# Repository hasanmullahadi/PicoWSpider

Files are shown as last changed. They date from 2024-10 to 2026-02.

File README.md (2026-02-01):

# PicoWRobotV1.2



**Robotics Prototyping Board for Raspberry Pi Pico W**

4 DC Motor Drivers | MPU-6050 Gyro | 16-Channel PWM | Dual USB-C Power

---

## Overview

Unlock the full potential of your Raspberry Pi Pico W with this versatile prototyping board designed specifically for fast, efficient robotics development. Perfect for hobbyists, students, and engineers, this board comes preloaded with advanced features to support even the most ambitious robotics projects.

## Key Features

| Feature | Description |
|---|---|
| **4 DC Motor Drivers** | 2x TB6612FNG for controlling up to 4 DC motors with dedicated USB-C power |
| **Built-in Gyroscope** | MPU-6050 6-axis gyro and accelerometer for orientation and motion tracking |
| **16-Channel PWM Driver** | PCA9685PW for precise servo control with dedicated USB-C power |
| **Dual USB-C Power** | Ideal Diode (LM66200DRLR) for safe, independent power to motors and servos |
| **RGB LED** | Common anode LED for status indication and visual effects |
| **4 Push Buttons** | Tactile switches for real-time user input |
| **Sensor Headers** | Pre-configured headers for OLED, ultrasonic, and I2C expansion |

## Pin Diagrams

### Motor Drivers (TB6612FNG)
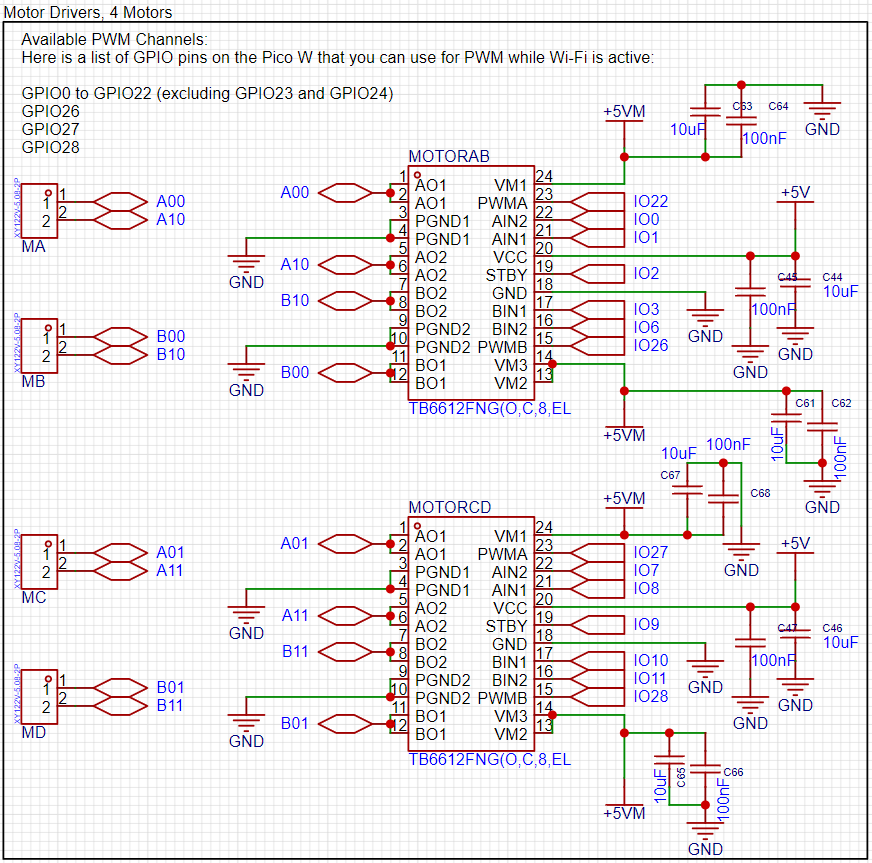
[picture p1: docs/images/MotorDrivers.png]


### Servo Connections (PCA9685)
<p>
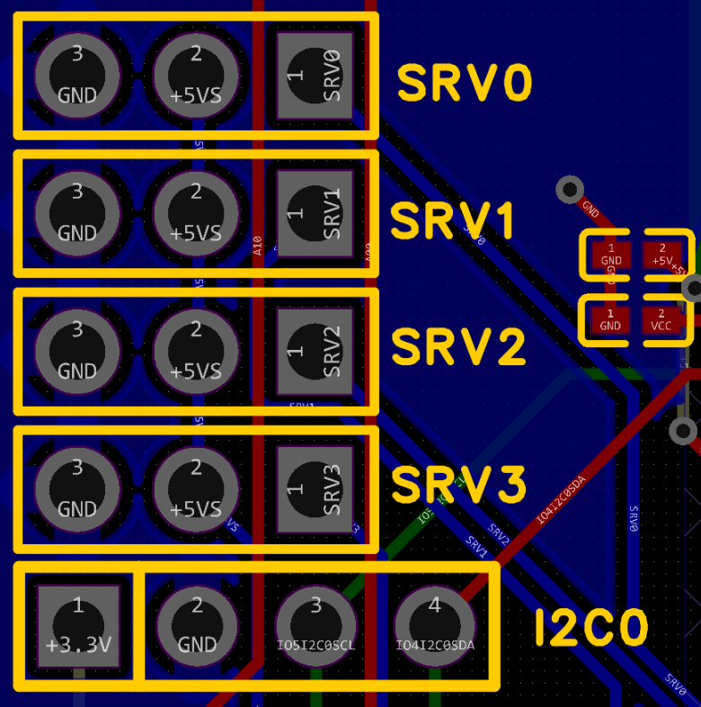
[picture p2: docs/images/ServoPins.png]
  
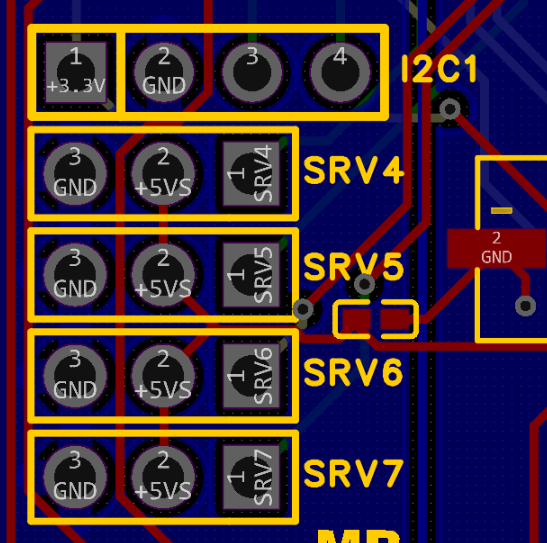
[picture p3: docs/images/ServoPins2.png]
  
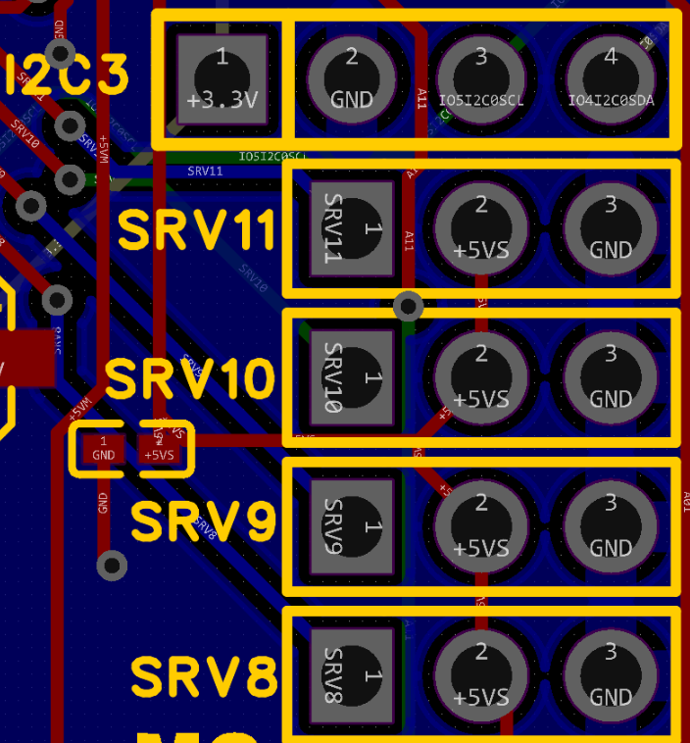
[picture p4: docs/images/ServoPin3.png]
  
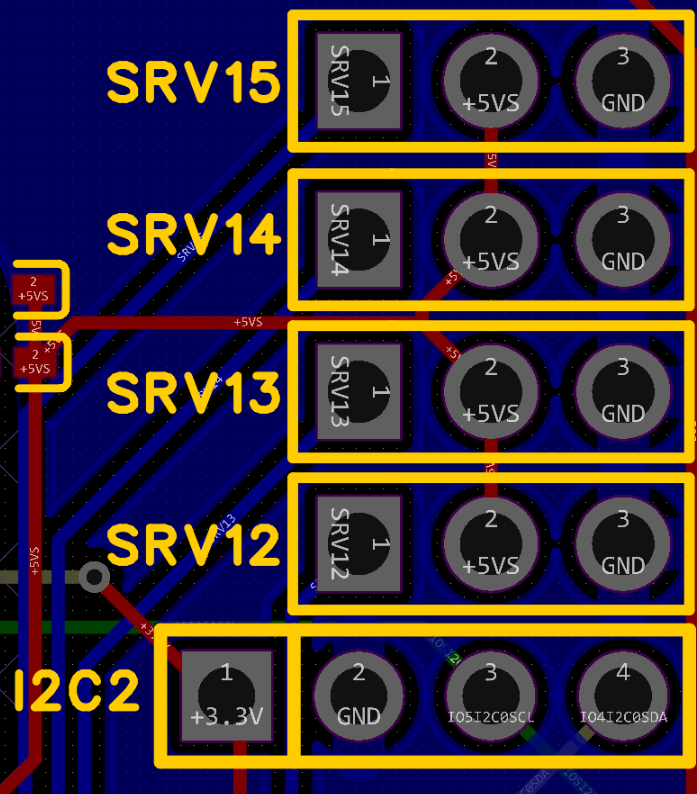
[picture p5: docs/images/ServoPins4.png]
  
</p>

### OLED Display
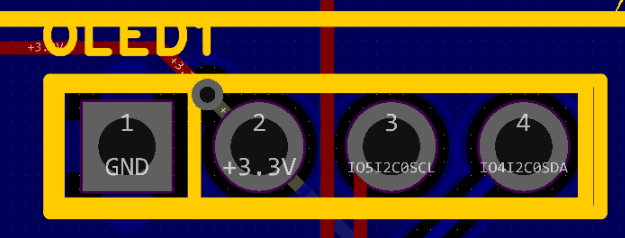
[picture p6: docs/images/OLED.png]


### Ultrasonic Sensor (HC-SR04)
<p>
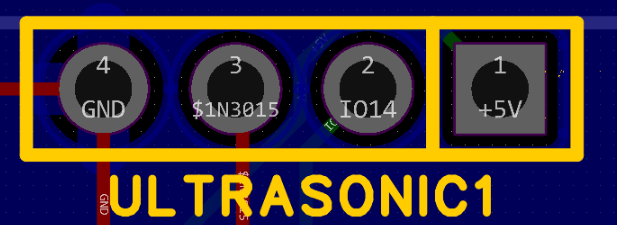
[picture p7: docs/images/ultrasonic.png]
  
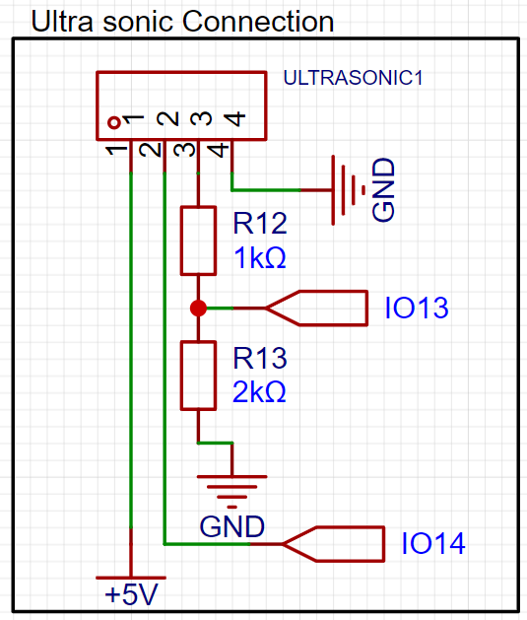
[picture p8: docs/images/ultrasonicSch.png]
  
</p>

### Temperature & Humidity Sensor (DHT22)
<p>
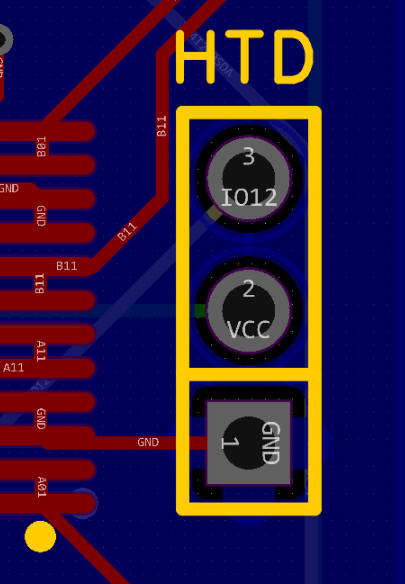
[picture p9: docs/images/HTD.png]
  
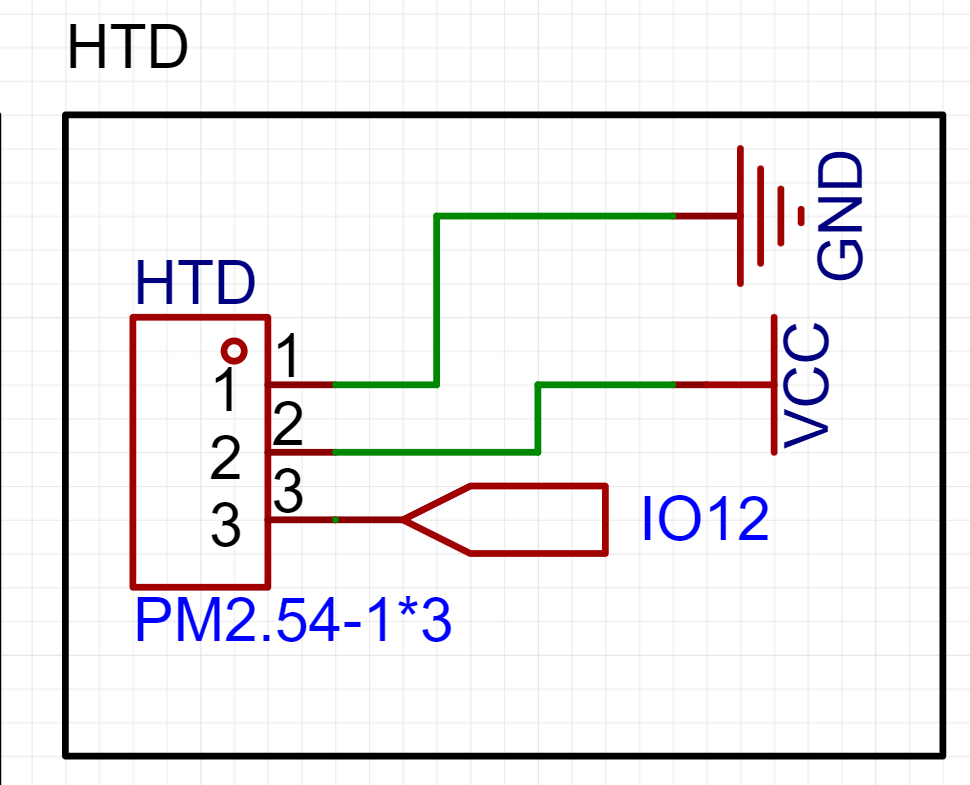
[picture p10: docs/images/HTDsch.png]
  
</p>

### RGB LED & Switches
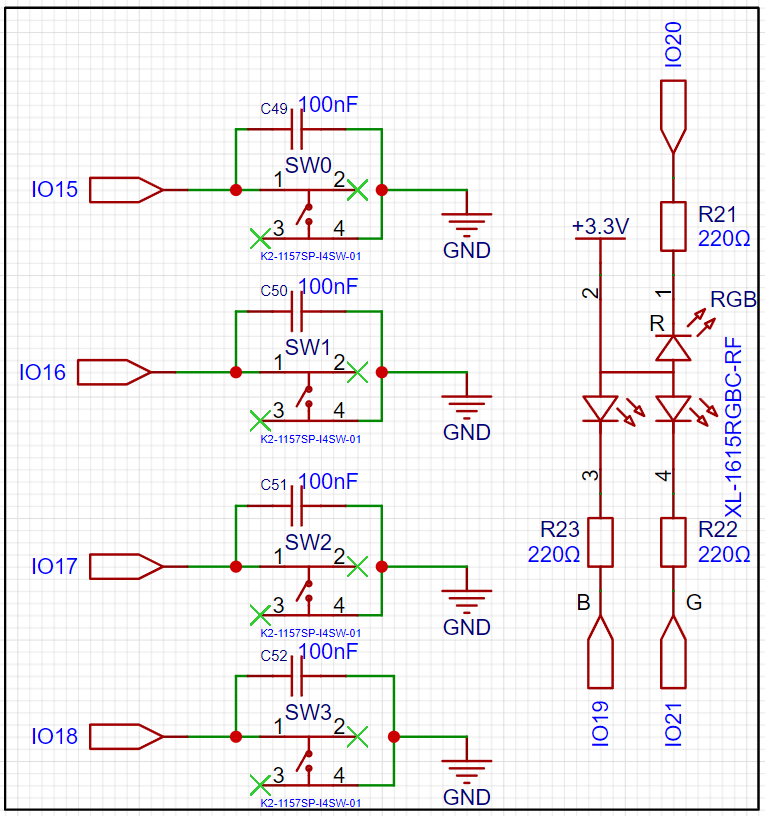
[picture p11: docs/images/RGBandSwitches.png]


## Dimensions

| Measurement | Value |
|---|---|
| PCB Size | 70.7mm x 110mm |
| PCB Weight | 58g (0.13 lbs) |
| Package Size | 20cm x 11cm x 13.5cm |
| Package Weight | 474g (1.05 lbs) |

## Bill of Materials

| # | Item | Description | Qty |
|---|---|---|-----|
| 1 | PicoWRobotV1.2 Board | Main prototyping board with motor drivers, gyro, PWM | 1 |
| 2 | RP Pico W | Raspberry Pi Pico W with pre-installed header pins | 1 |
| 3 | Ultrasonic Module | HC-SR04 distance sensor | 1 |
| 4 | TT Motor | DC motors for drive system | 4 |
| 5 | Mecanum Wheels | Omni-directional wheels with extensions and screws (2L, 2R) | 4 |
| 6 | DHT22 | Temperature and humidity sensor | 1 |
| 7 | OLED | 128x64 pixel display module | 1 |
| 8 | 3D Printed Body | Chassis (STL file: `docs/PicoWv1.stl`) | 1 |
| 9 | USB-C to USB Cable | For powering the board | 2 |
| 10 | USB to Micro USB Cable | For programming the Pico W | 1 |
| 11 | Zip Ties | For securing components and power bank | 5 |
| 12 | M3 Plastic Screws | With nuts for assembly | 3 |

## Getting Started

### Requirements
- Arduino IDE
- Power bank (not included) - must use standard USB output and be narrower than 6.5cm

### Arduino Libraries
Install via Library Manager:
- Adafruit GFX Library
- Adafruit SSD1306
- Adafruit MPU6050
- Adafruit PWM Servo Driver Library
- DHT sensor library

### Upload
1. Open `PicoWSpider.ino` in Arduino IDE
2. Select Board: **Raspberry Pi Pico W**
3. Connect via USB and upload

### WiFi Control
The robot creates a WiFi access point on boot:
- **SSID:** PicoW
- **Password:** 12345678
- **Control Interface:** Connect and navigate to the IP shown on the OLED display

## 3D Model

The chassis STL file (`docs/PicoWv1.stl`) is included for 3D printing your own robot body.

## Author

**Hasan Ismail** · [@hasanmullahadi](https://github.com/hasanmullahadi)

I'm a passionate hobbyist who loves creating and building projects, especially in robotics. My goal with this development board is to make it as fast and easy as possible for anyone to start coding and experimenting with robotics.

Your feedback and suggestions are welcome for future versions!

**Contact:** [Open an issue](https://github.com/hasanmullahadi/PicoWSpider/issues) or reach out via GitHub

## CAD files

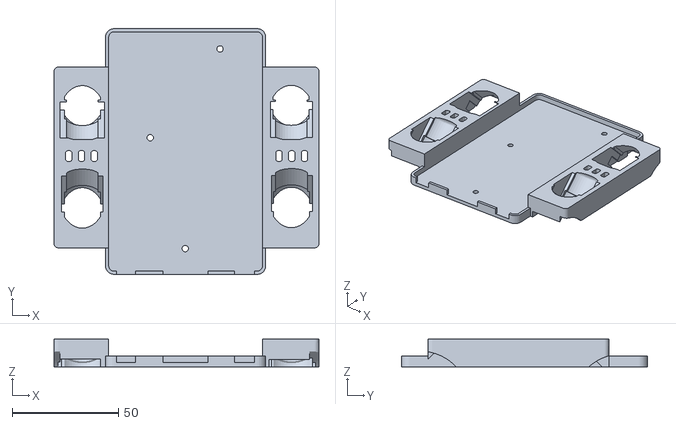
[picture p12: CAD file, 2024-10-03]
docs/PicoWv1.stl
124.8 x 115.7 x 13.1

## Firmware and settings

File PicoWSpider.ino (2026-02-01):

#include <Adafruit_GFX.h>
#include <Adafruit_SSD1306.h>
#include <Adafruit_MPU6050.h>

#include "src/web/RobotWebServer.h"
#include "src/actuators/MotorController.h"
#include "src/actuators/ServoController.h"
#include "src/sensors/DHTSensor.h"
#include "src/sensors/Ultrasonic.h"

// ============================================================================
// Configuration Constants
// ============================================================================

// WiFi
const char *WIFI_SSID = "PicoW";
const char *WIFI_PASSWORD = "12345678";

// Motor speeds
const uint8_t MOTOR_SPEED_NORMAL = 150;
const uint8_t MOTOR_SPEED_SLOW = 100;
const uint8_t MOTOR_SPEED_FAST = 200;

// Timing intervals (ms)
const unsigned long DISPLAY_UPDATE_INTERVAL = 250;
const unsigned long SERVO_UPDATE_INTERVAL = 1000;
const unsigned long OBSTACLE_CLEAR_DELAY = 1000;
const unsigned long TURN_360_DURATION = 3000;

// Obstacle detection threshold (cm)
const float OBSTACLE_DISTANCE_CM = 30.0;

// OLED display
const int SCREEN_WIDTH = 128;
const int SCREEN_HEIGHT = 64;
const int SCREEN_ADDRESS = 0x3C;

// ============================================================================
// Pin Definitions
// ============================================================================

// Motor Controller AB
#define PWMA_PIN 22
#define AIN1_PIN 1
#define AIN2_PIN 0
#define PWMB_PIN 26
#define BIN1_PIN 3
#define BIN2_PIN 6
#define STBY_PIN_AB 2

// Motor Controller CD
#define PWMC_PIN 27
#define CIN1_PIN 8
#define CIN2_PIN 7
#define PWMD_PIN 28
#define DIN1_PIN 10
#define DIN2_PIN 11
#define STBY_PIN_CD 9

// Sensors
#define TRIG_PIN 14
#define ECHO_PIN 13
#define DHT_PIN 12
#define DHT_TYPE DHT22

// User interface
#define BUTTON_0 15
#define BUTTON_1 16
#define BUTTON_2 17
#define BUTTON_3 18
#define LED_RED 20
#define LED_GREEN 21
#define LED_BLUE 19

// Servo channels
#define SRV0 0
#define SRV15 15

// ============================================================================
// Global Objects
// ============================================================================

RobotWebServer robotServer(WIFI_SSID, WIFI_PASSWORD, 80, true);
MotorController motorControllerAB(PWMA_PIN, AIN2_PIN, AIN1_PIN, PWMB_PIN, BIN2_PIN, BIN1_PIN, STBY_PIN_AB);
MotorController motorControllerCD(PWMC_PIN, CIN1_PIN, CIN2_PIN, PWMD_PIN, DIN1_PIN, DIN2_PIN, STBY_PIN_CD);
Ultrasonic ultrasonic(TRIG_PIN, ECHO_PIN);
ServoController servoController(0x60);
DHTSensor dhtSensor(DHT_PIN, DHT_TYPE);
Adafruit_SSD1306 display(SCREEN_WIDTH, SCREEN_HEIGHT, &Wire, -1);
Adafruit_MPU6050 mpu;

// State variables
unsigned long previousDisplayMillis = 0;
unsigned long previousServoMillis = 0;
unsigned long obstacleClearMillis = 0;
unsigned long turnStartMillis = 0;
float distance = 0;
float humidity = 0;
float temperature = 0;
int brightness = 255;
bool isSpinning = false;
bool spinDirection = false;
bool isTurning = false;
bool servoMoveRight = false;

// ============================================================================
// Setup
// ============================================================================

void setup() {
    Serial.begin(115200);

    // Initialize MPU6050
    if (!mpu.begin()) {
        Serial.println("Failed to find MPU6050 chip");
        while (1) delay(10);
    }
    Serial.println("MPU6050 Found!");

    mpu.setHighPassFilter(MPU6050_HIGHPASS_0_63_HZ);
    mpu.setMotionDetectionThreshold(1);
    mpu.setMotionDetectionDuration(20);
    mpu.setInterruptPinLatch(true);
    mpu.setInterruptPinPolarity(true);
    mpu.setMotionInterrupt(true);

    // Initialize sensors
    ultrasonic.begin();
    dhtSensor.begin();

    // Initialize buttons
    pinMode(BUTTON_0, INPUT_PULLUP);
    pinMode(BUTTON_1, INPUT_PULLUP);
    pinMode(BUTTON_2, INPUT_PULLUP);
    pinMode(BUTTON_3, INPUT_PULLUP);

    // Initialize RGB LED (common anode - inverted)
    pinMode(LED_RED, OUTPUT);
    pinMode(LED_GREEN, OUTPUT);
    pinMode(LED_BLUE, OUTPUT);

    // Initialize I2C and OLED
    Wire.begin();
    if (!display.begin(SSD1306_SWITCHCAPVCC, SCREEN_ADDRESS)) {
        for (;;);
    }

    display.clearDisplay();
    display.setTextSize(1);
    display.setTextColor(SSD1306_WHITE);
    display.setCursor(0, 0);
    display.println(F("Mini Robot"));
    display.display();
    delay(2000);

    // Initialize servo controller
    servoController.begin();
    servoController.moveServo(SRV0, 90);
    servoController.moveServo(SRV15, 90);

    // Initialize motor controllers
    motorControllerAB.begin();
    motorControllerCD.begin();
    delay(1000);

    // Start web server
    robotServer.begin();

    String ipAddress = WiFi.localIP().toString();
    Serial.print("IP Address: ");
    Serial.println(ipAddress);

    display.clearDisplay();
    display.setCursor(0, 0);
    display.println(F("Connected to WiFi"));
    display.setCursor(0, 20);
    display.println(F("IP Address:"));
    display.setCursor(0, 35);
    display.println(ipAddress);
    display.display();

    // Set web server callbacks
    robotServer.setMoveForwardCallback(moveForward);
    robotServer.setMoveBackwardCallback(moveBackward);
    robotServer.setStopCallback(stopMotors);
    robotServer.setSpinCallback(spin);
}

// ============================================================================
// Main Loop
// ============================================================================

void loop() {
    unsigned long currentMillis = millis();

    // Update display and sensors
    if (currentMillis - previousDisplayMillis >= DISPLAY_UPDATE_INTERVAL) {
        previousDisplayMillis = currentMillis;
        updateDisplayAndSensors();
    }

    // Update servo positions
    if (currentMillis - previousServoMillis >= SERVO_UPDATE_INTERVAL) {
        previousServoMillis = currentMillis;
        updateServos();
    }

    // Update IMU data
    if (mpu.getMotionInterruptStatus()) {
        sensors_event_t a, g, temp;
        mpu.getEvent(&a, &g, &temp);
        robotServer.setAcceleration(a.acceleration.x, a.acceleration.y, a.acceleration.z);
        robotServer.setGyroscope(g.gyro.x, g.gyro.y, g.gyro.z);
    }

    // Update web server data
    updateLEDsFromServer();
    robotServer.setDistance(distance);
    robotServer.setDHTValues(temperature, humidity);
    robotServer.handleClient();
}

// ============================================================================
// Display & Sensor Updates
// ============================================================================

void updateDisplayAndSensors() {
    display.clearDisplay();

    // Read sensors
    temperature = dhtSensor.readTemperature();
    humidity = dhtSensor.readHumidity();
    distance = ultrasonic.getDistance();

    // Display temperature and humidity
    display.setTextSize(1);
    display.setTextColor(SSD1306_WHITE);
    display.setCursor(0, 0);
    display.print(F("T: "));
    display.print(temperature);
    display.print(F("C, H: "));
    display.print(humidity);
    display.println(F("%"));

    // Handle button presses
    handleButtons();

    // Display distance
    display.setCursor(0, 32);
    display.print(F("Distance: "));
    display.print(distance);
    display.println(F(" cm"));

    // Display IP
    display.setCursor(0, 48);
    display.print(F("IP: "));
    display.println(WiFi.localIP().toString());

    display.display();
}

void handleButtons() {
    if (digitalRead(BUTTON_0) == LOW) {
        displayButton(0);
        setRGB(LOW, HIGH, HIGH);  // Red
    } else if (digitalRead(BUTTON_1) == LOW) {
        displayButton(1);
        setRGB(HIGH, LOW, HIGH);  // Green
    } else if (digitalRead(BUTTON_2) == LOW) {
        displayButton(2);
        setRGB(HIGH, HIGH, LOW);  // Blue
    } else if (digitalRead(BUTTON_3) == LOW) {
        displayButton(3);
        toggleBrightness();
    }
}

void displayButton(int buttonNumber) {
    display.setCursor(0, 16);
    display.print(F("Button "));
    display.print(buttonNumber);
    display.println(F(" pressed"));
}

// ============================================================================
// LED Control
// ============================================================================

void setRGB(int red, int green, int blue) {
    // Common anode: invert values
    analogWrite(LED_RED, 255 - red);
    analogWrite(LED_GREEN, 255 - green);
    analogWrite(LED_BLUE, 255 - blue);
}

void toggleBrightness() {
    brightness = (brightness == 255) ? 128 : 255;
    analogWrite(LED_RED, brightness);
    analogWrite(LED_GREEN, brightness);
    analogWrite(LED_BLUE, brightness);
}

void updateLEDsFromServer() {
    uint8_t r, g, b;
    robotServer.getRGBValue(0, r, g, b);
    setRGB(r, g, b);
}

// ============================================================================
// Servo Control
// ============================================================================

void updateServos() {
    if (servoMoveRight) {
        servoController.moveRight(SRV0);
        servoController.moveRight(SRV15);
    } else {
        servoController.moveLeft(SRV0);
        servoController.moveLeft(SRV15);
    }
    servoMoveRight = !servoMoveRight;
}

// ============================================================================
// Motor Control - Basic Movements
// ============================================================================

void moveForward() {
    motorControllerAB.motorAForward(MOTOR_SPEED_NORMAL);
    motorControllerAB.motorBForward(MOTOR_SPEED_NORMAL);
    motorControllerCD.motorAForward(MOTOR_SPEED_NORMAL);
    motorControllerCD.motorBForward(MOTOR_SPEED_NORMAL);
}

void moveBackward() {
    motorControllerAB.motorABackward(MOTOR_SPEED_NORMAL);
    motorControllerAB.motorBBackward(MOTOR_SPEED_NORMAL);
    motorControllerCD.motorABackward(MOTOR_SPEED_NORMAL);
    motorControllerCD.motorBBackward(MOTOR_SPEED_NORMAL);
}

void strafeRight() {
    motorControllerAB.motorAForward(MOTOR_SPEED_NORMAL);
    motorControllerAB.motorBBackward(MOTOR_SPEED_NORMAL);
    motorControllerCD.motorABackward(MOTOR_SPEED_NORMAL);
    motorControllerCD.motorBForward(MOTOR_SPEED_NORMAL);
}

void strafeLeft() {
    motorControllerAB.motorABackward(MOTOR_SPEED_NORMAL);
    motorControllerAB.motorBForward(MOTOR_SPEED_NORMAL);
    motorControllerCD.motorAForward(MOTOR_SPEED_NORMAL);
    motorControllerCD.motorBBackward(MOTOR_SPEED_NORMAL);
}

void stopMotors() {
    motorControllerAB.motorAStop();
    motorControllerAB.motorBStop();
    motorControllerCD.motorAStop();
    motorControllerCD.motorBStop();
}

// ============================================================================
// Motor Control - Spinning
// ============================================================================

void spin() {
    spinLeftSlow();
}

void spinLeftSlow() {
    motorControllerAB.motorAForward(MOTOR_SPEED_SLOW);
    motorControllerAB.motorBForward(MOTOR_SPEED_SLOW);
    motorControllerCD.motorABackward(MOTOR_SPEED_SLOW);
    motorControllerCD.motorBBackward(MOTOR_SPEED_SLOW);
}

void spinRightSlow() {
    motorControllerAB.motorABackward(MOTOR_SPEED_SLOW);
    motorControllerAB.motorBBackward(MOTOR_SPEED_SLOW);
    motorControllerCD.motorAForward(MOTOR_SPEED_SLOW);
    motorControllerCD.motorBForward(MOTOR_SPEED_SLOW);
}

void performSlowSpin(bool direction) {
    if (direction) {
        spinRightSlow();
    } else {
        spinLeftSlow();
    }
}

// ============================================================================
// Autonomous Navigation
// ============================================================================

void movingAround() {
    unsigned long currentMillis = millis();

    if (ultrasonic.getDistance() < OBSTACLE_DISTANCE_CM) {
        if (!isSpinning) {
            isSpinning = true;
            spinDirection = random(0, 2);
        }
        performSlowSpin(spinDirection);
        obstacleClearMillis = currentMillis;
    } else {
        if (isSpinning && (currentMillis - obstacleClearMillis >= OBSTACLE_CLEAR_DELAY)) {
            isSpinning = false;
        }
        if (!isSpinning) {
            moveForward();
        }
    }
}

void perform360Turn() {
    unsigned long currentMillis = millis();

    if (!isTurning) {
        motorControllerAB.motorAForward(MOTOR_SPEED_NORMAL);
        motorControllerAB.motorBBackward(MOTOR_SPEED_NORMAL);
        motorControllerCD.motorABackward(MOTOR_SPEED_NORMAL);
        motorControllerCD.motorBForward(MOTOR_SPEED_NORMAL);
        turnStartMillis = currentMillis;
        isTurning = true;
    }

    if (isTurning && (currentMillis - turnStartMillis >= TURN_360_DURATION)) {
        stopMotors();
        isTurning = false;
    }
}

// ============================================================================
// Testing & Diagnostics
// ============================================================================

void displayStatus(const char *status) {
    display.clearDisplay();
    display.setTextSize(1);
    display.setTextColor(SSD1306_WHITE);
    display.setCursor(0, 0);
    display.println(F("Status:"));
    display.println(status);
    display.display();
}

void testMotors() {
    displayStatus("Testing Motor A");
    motorControllerAB.softStartA(128);
    delay(1000);
    motorControllerAB.softStopA();
    delay(1000);

    displayStatus("Testing Motor B");
    motorControllerAB.softStartB(128);
    delay(1000);
    motorControllerAB.softStopB();
    delay(1000);

    displayStatus("Testing Motor C");
    motorControllerCD.softStartA(128);
    delay(1000);
    motorControllerCD.softStopA();
    delay(1000);

    displayStatus("Testing Motor D");
    motorControllerCD.softStartB(128);
    delay(1000);
    motorControllerCD.softStopB();
    delay(1000);
}

void forwardTest() {
    const char* motorNames[] = {"Front Left (A)", "Back Left (B)", "Back Right (C)", "Front Right (D)"};

    displayStatus(motorNames[0]);
    motorControllerAB.motorAForward(MOTOR_SPEED_FAST);
    delay(2000);
    motorControllerAB.motorAStop();
    delay(1000);

    displayStatus(motorNames[1]);
    motorControllerAB.motorBForward(MOTOR_SPEED_FAST);
    delay(2000);
    motorControllerAB.motorBStop();
    delay(1000);

    displayStatus(motorNames[2]);
    motorControllerCD.motorAForward(MOTOR_SPEED_FAST);
    delay(2000);
    motorControllerCD.motorAStop();
    delay(1000);

    displayStatus(motorNames[3]);
    motorControllerCD.motorBForward(MOTOR_SPEED_FAST);
    delay(2000);
    motorControllerCD.motorBStop();
    delay(1000);

    displayStatus("Forward Test Complete");
    delay(2000);
}

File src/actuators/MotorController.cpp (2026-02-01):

#include "MotorController.h"

MotorController::MotorController(uint8_t pwmaPin, uint8_t ain1Pin, uint8_t ain2Pin,
                                 uint8_t pwmbPin, uint8_t bin1Pin, uint8_t bin2Pin,
                                 uint8_t stbyPin)
    : _pwmaPin(pwmaPin), _ain1Pin(ain1Pin), _ain2Pin(ain2Pin),
      _pwmbPin(pwmbPin), _bin1Pin(bin1Pin), _bin2Pin(bin2Pin),
      _stbyPin(stbyPin) {}

void MotorController::begin() {
    pinMode(_pwmaPin, OUTPUT);
    pinMode(_ain1Pin, OUTPUT);
    pinMode(_ain2Pin, OUTPUT);
    pinMode(_pwmbPin, OUTPUT);
    pinMode(_bin1Pin, OUTPUT);
    pinMode(_bin2Pin, OUTPUT);
    pinMode(_stbyPin, OUTPUT);
    wake();
}

void MotorController::motorAForward(uint8_t speed) {
    motorControl(_pwmaPin, _ain1Pin, _ain2Pin, speed, true);
}

void MotorController::motorABackward(uint8_t speed) {
    motorControl(_pwmaPin, _ain1Pin, _ain2Pin, speed, false);
}

void MotorController::motorAStop() {
    analogWrite(_pwmaPin, 0);
}

void MotorController::motorBForward(uint8_t speed) {
    motorControl(_pwmbPin, _bin1Pin, _bin2Pin, speed, true);
}

void MotorController::motorBBackward(uint8_t speed) {
    motorControl(_pwmbPin, _bin1Pin, _bin2Pin, speed, false);
}

void MotorController::motorBStop() {
    analogWrite(_pwmbPin, 0);
}

void MotorController::standby() {
    digitalWrite(_stbyPin, LOW);
}

void MotorController::wake() {
    digitalWrite(_stbyPin, HIGH);
}

void MotorController::softStartA(uint8_t targetSpeed, uint8_t incrementDelay) {
    static unsigned long previousMillis = 0;
    static uint8_t currentSpeed = 0;
    unsigned long currentMillis = millis();

    if (currentSpeed < targetSpeed && (currentMillis - previousMillis >= incrementDelay)) {
        previousMillis = currentMillis;
        currentSpeed += SPEED_INCREMENT;
        motorAForward(currentSpeed);
    }
}

void MotorController::softStopA(uint8_t decrementDelay) {
    static unsigned long previousMillis = 0;
    static uint8_t currentSpeed = analogRead(_pwmaPin);
    unsigned long currentMillis = millis();

    if (currentSpeed > 0 && (currentMillis - previousMillis >= decrementDelay)) {
        previousMillis = currentMillis;
        currentSpeed = (currentSpeed > SPEED_INCREMENT) ? currentSpeed - SPEED_INCREMENT : 0;
        motorAForward(currentSpeed);
    }
    if (currentSpeed == 0) {
        motorAStop();
    }
}

void MotorController::softStartB(uint8_t targetSpeed, uint8_t incrementDelay) {
    static unsigned long previousMillis = 0;
    static uint8_t currentSpeed = 0;
    unsigned long currentMillis = millis();

    if (currentSpeed < targetSpeed && (currentMillis - previousMillis >= incrementDelay)) {
        previousMillis = currentMillis;
        currentSpeed += SPEED_INCREMENT;
        motorBForward(currentSpeed);
    }
}

void MotorController::softStopB(uint8_t decrementDelay) {
    static unsigned long previousMillis = 0;
    static uint8_t currentSpeed = analogRead(_pwmbPin);
    unsigned long currentMillis = millis();

    if (currentSpeed > 0 && (currentMillis - previousMillis >= decrementDelay)) {
        previousMillis = currentMillis;
        currentSpeed = (currentSpeed > SPEED_INCREMENT) ? currentSpeed - SPEED_INCREMENT : 0;
        motorBForward(currentSpeed);
    }
    if (currentSpeed == 0) {
        motorBStop();
    }
}

void MotorController::motorControl(uint8_t pwmPin, uint8_t in1Pin, uint8_t in2Pin,
                                   uint8_t speed, bool forward) {
    analogWrite(pwmPin, speed);
    if (forward) {
        digitalWrite(in1Pin, HIGH);
        digitalWrite(in2Pin, LOW);
    } else {
        digitalWrite(in1Pin, LOW);
        digitalWrite(in2Pin, HIGH);
    }
}

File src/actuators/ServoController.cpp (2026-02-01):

#include "ServoController.h"

ServoController::ServoController(uint8_t addr) : pwm(Adafruit_PWMServoDriver(addr)) {}

void ServoController::begin() {
    pwm.begin();
    pwm.setPWMFreq(SERVO_FREQ_HZ);
}

void ServoController::moveServo(uint8_t servoNum, uint16_t angle) {
    uint16_t clampedAngle = constrain(angle, SERVO_ANGLE_MIN, SERVO_ANGLE_MAX);
    uint16_t pulseLength = map(clampedAngle, SERVO_ANGLE_MIN, SERVO_ANGLE_MAX,
                               SERVO_MIN_PULSE, SERVO_MAX_PULSE);
    pwm.setPWM(servoNum, 0, pulseLength);
}

void ServoController::moveLeft(uint8_t servoNum) {
    moveServo(servoNum, SERVO_ANGLE_MIN);
}

void ServoController::moveRight(uint8_t servoNum) {
    moveServo(servoNum, SERVO_ANGLE_MAX);
}

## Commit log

2026-02-01 Improve README formatting and add CLAUDE.md
    - Restructure README with proper Markdown tables
    - Add pin diagram images for all hardware components
    - Fix BOM table and add Getting Started section
    - Add CLAUDE.md for Claude Code guidance
2026-02-01 Resize images in README for better layout
    - Add width constraints to all images
    - Group related images side-by-side
    - Servo pins now display in 2x2 grid
2026-02-01 Refactor codebase for cleaner architecture
    DRY improvements:
    - Extract magic numbers to named constants (motor speeds, servo limits, timing)
    - Fix RGB array size mismatch (was [1] but checking for 5)
    - Remove duplicate stopAllMotors() function
    Code quality:
    - Remove obvious "WHAT" comments, keep only "WHY" comments
    - Add input validation (servo angle clamping)
    - Fix potential underflow in softStop functions
    - Organize main .ino with clear section headers
    - Consolidate includes at top of main file
    Bug fixes:
    - Fix softStop underflow when currentSpeed < SPEED_INCREMENT
    - Fix RGB LED selector (only 1 LED, not 5)
    - Consistent header guard naming (UPPERCASE_H format)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
    [MotorController.cpp, PicoWSpider.ino, RobotWebServer.cpp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]
2026-02-01 Organize project folder structure
    - Move images to docs/images/
    - Move STL file to docs/
    - Move style.css to docs/ (reference only, embedded in code)
    - Update README.md with new image paths
    - Remove empty 'images' placeholder file
    [PicoWv1.stl]
2026-02-01 Add CLI compile instructions to CLAUDE.md
    - Add arduino-cli setup and compile commands
    - Document project folder structure
    - Simplify architecture section
2026-02-01 Organize source into src/ subfolders with CI
    Project structure:
    - src/actuators/ - MotorController, ServoController
    - src/sensors/ - DHTSensor, Ultrasonic
    - src/web/ - RobotWebServer, html, css
    Added:
    - GitHub Actions workflow for automatic compilation
    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
